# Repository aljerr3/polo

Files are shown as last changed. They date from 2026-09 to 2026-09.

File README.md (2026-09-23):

# 🪲 POLO — Walking Beetle Robot / Escarabajo Robot Caminante

<p align="center">
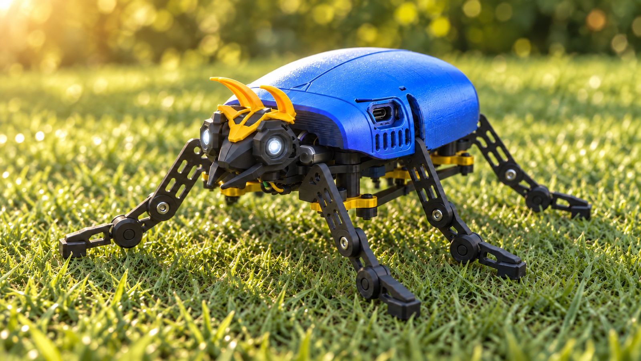
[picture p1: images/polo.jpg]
POLO — Walking Beetle Robot
  
</p>

<p align="center">
  <b><a href="#-english">🇬🇧 English</a> · <a href="#-español">🇪🇸 Español</a></b>
</p>

---

## 🇬🇧 English

Can a six-legged robot be made to walk with just three motors? **POLO** is a **fully 3D-printable** beetle robot, inspired by the *pololo* —a Chilean beetle— and by the minimalist walkers of **Mark Tilden**, to whom this project pays tribute.

This isn't just an electronics project. It's an exercise in mechanics: print-in-place ball joints, lobular couplers, connecting rods and a central rocker that, together, make six legs move in a fluid, almost organic way.

### 🎯 What does this robot do?

- Walks forward, backward and turns using **only 3 servos**
- Controlled from your phone **over WiFi, no apps**, straight from the browser
- Has **4 walking speeds**: very fast, fast, slow and stealthy
- Its eyes pulse, simulating a beetle's heartbeat
- Emits **stridulation** sounds through a buzzer, just like real beetles
- Charges via **USB-C** without removing the shell

### ⚙️ Main components

| Component | Detail |
|---|---|
| Microcontroller | ESP32-C3 Super Mini |
| Actuators | 3 × SG90 servos |
| Battery | 803040 LiPo, 1000 mAh (3.7 V) |
| Power management | PB0063A module (IP5306): charging, protection and 5 V boost |
| Filtering | 470 µF electrolytic capacitor |
| Eyes | 2 × 5 mm LEDs |
| Sound | Passive buzzer |
| PCB | POLO PCB (manufactured by PCBWay) or hand-built on perfboard |
| Structure | 3D-printed parts (PLA) |

### 🧠 Philosophy behind the project

Today electronics and software are within anyone's reach, especially with the help of AI. Mechanics, on the other hand, still surprises. That's why the heart of POLO is not in the code, but in how its parts move.

The robot draws on **BEAM**, Mark Tilden's philosophy: achieving complex behaviors with the fewest possible components. One servo moves both legs on the left side, another the right side, and a third drives a central rocker that tilts the body to lift the legs on the opposite side.

POLO is also a learning project. A walker like this can be made with 2 servos, and probably better. This is my path toward that, and I'm sharing it in full so others can improve it.

### 🔩 Mechanical features

- **100% printable**: all structural parts are 3D-printed
- Print-in-place articulated ball joints, in a single piece and **without supports**: the ankle drops about 45° when the leg lifts and self-levels when it lands
- Elongated flat-soled feet for better traction
- Indexed 10-lobe lobular couplers (36° steps) to adjust the position of each tibia
- Mechanical connecting rods and a central rocker driven by the same 3 servos
- Topology optimization to reduce weight, material and power consumption
- Elytra-style shell screwed to the chassis, with openings for the USB-C ports
- Snap-on helmet with horns that double as antennae
- Size: about **12.6 cm** from leg tip to leg tip

### 📡 Technical features

- **WiFi in access-point mode**: the robot creates its own network, no router needed
- Responsive web interface with two views: **control** and **configuration**
- Low-latency control: hold an arrow to walk and release to return to rest
- Servo calibration and gait routines (angles and speed) from the browser
- Default values measured with an oscilloscope, ready for anyone who can't calibrate
- Independent control of each eye with PWM dimming
- Free **I2C (Qwiic)** port so you can add your own sensors
- Measured consumption: **~0.36 A at 5 V (1.75 W)**

### 🔌 Electrical connections

**ESP32-C3 Super Mini:**

| GPIO | Function |
|---|---|
| GPIO 4 | Left leg servo |
| GPIO 3 | Right leg servo |
| GPIO 2 | Central rocker servo |
| GPIO 10 | LED eye 1 (cathode; anode to 5 V through a resistor) |
| GPIO 1 | LED eye 2 (cathode; anode to 5 V through a resistor) |
| GPIO 7 | Buzzer (signal S) |
| GPIO 5 | SDA (Qwiic port) |
| GPIO 6 | SCL (Qwiic port) |

**Power:** LiPo battery → IP5306 module → 5 V rail. The ESP32 and the 3 servos share the 5 V rail, with a 470 µF capacitor.

See the full schematic in [`hardware/Esquematico.png`](hardware/Esquematico.png).

### 🛠️ Build your own PCB with PCBWay

POLO's board is designed to fit exactly into the chassis. It's 2-layer and measures **50.1 × 40.3 mm**, with an outline cut to the robot's shape. It has a black solder mask and white silkscreen, easy-to-solder through-hole components, ground planes on both sides and two USB-C ports (charging and programming).

Thanks to **PCBWay**, sponsor of this project's PCB, you can order the same board directly from their platform. The Gerber files are in [`hardware/Gerber_POLO_PCB.zip`](hardware/Gerber_POLO_PCB.zip).

If you prefer to build it by hand, POLO's first prototype worked perfectly on **perfboard**.

### 🚀 Installation and setup

1. Print the parts (recommended: PLA, 0.12 mm layer height; the ball-jointed tibias are printed flat-side down on the bed, without supports)
2. Solder the PCB or build the circuit on perfboard according to the schematic
3. Flash the firmware ([`firmware/POLO_v7_1.ino`](firmware/POLO_v7_1.ino)) onto the ESP32-C3 via the programming USB-C port
4. Mount the servos in their rest position before attaching the legs
5. Power on POLO and connect from your phone to its WiFi network
6. Open the robot's IP in your browser
7. In the configuration view, adjust the rest position and gait if needed
8. Switch to the control view and make it walk!

**Customizable configuration (from the web):** rest position of each servo (default **60° / 111° / 68°**), swing angles for forward/backward/turn, gait period (default **700 ms**), walking speeds, and eyes on/off + brightness.

### 📁 Repository contents

```
polo/
├── firmware/
│   └── POLO_v7_1.ino          # Firmware for the ESP32-C3
├── hardware/
│   ├── Esquematico.png         # Circuit schematic
│   ├── PCB_Diseno.png          # PCB design
│   └── Gerber_POLO_PCB.zip     # Gerber files for manufacturing
├── 3d/
│   ├── POLO.step               # Full CAD model (Fusion 360 / STEP)
│   ├── POLO_impresion_orcaslicer.3mf  # OrcaSlicer print profile & plate layout
│   ├── polo-stl.zip            # All STL parts
│   └── stl/                    # Individual STL parts
└── images/                     # Robot photos
```

> **3D printing:** the CAD model, STL files and my OrcaSlicer print profile are in [`3d/`](3d/). **Please read the [printing notes and disclaimer](3d/README.md) first.**

### 🧰 Technologies

ESP32-C3 · SG90 servos · 3D printing · Fusion 360 · EasyEDA · PCBWay · WiFi AP · Embedded web server · PWM · I2C

### 📜 License

This project is released under the **MIT** license. You can modify, adapt and improve it. See [LICENSE](LICENSE).

---

## 🇪🇸 Español

¿Se puede hacer caminar un robot de seis patas con solo tres motores? **POLO** es un escarabajo robot **100% imprimible**, inspirado en el *pololo* —un escarabajo chileno— y en los caminantes minimalistas de **Mark Tilden**, a quien este proyecto rinde tributo.

Este no es solo un proyecto de electrónica. Es un ejercicio de mecánica: rótulas impresas en una sola pieza, acoples lobulares, bielas y un balancín que, juntos, hacen que seis patas se muevan de forma fluida y casi orgánica.

### 🎯 ¿Qué hace este robot?

- Camina hacia adelante, hacia atrás y gira usando **solo 3 servos**
- Se controla desde el celular **por WiFi, sin apps**, directo desde el navegador
- Tiene **4 velocidades de marcha**: muy rápido, rápido, lento y sigiloso
- Sus ojos pulsan simulando el latido del corazón de un escarabajo
- Emite sonidos de **estridulación** con un buzzer, igual que los escarabajos reales
- Se carga por **USB-C** sin quitar el caparazón

### ⚙️ Componentes principales

| Componente | Detalle |
|---|---|
| Microcontrolador | ESP32-C3 Super Mini |
| Actuadores | 3 servos SG90 |
| Batería | LiPo 803040 de 1000 mAh (3,7 V) |
| Gestión de energía | Módulo PB0063A (IP5306): carga, protección y elevador a 5 V |
| Filtrado | Condensador electrolítico de 470 µF |
| Ojos | 2 LEDs de 5 mm |
| Sonido | Buzzer pasivo |
| PCB | POLO PCB (fabricada por PCBWay) o perfboard armada a mano |
| Estructura | Piezas impresas en 3D (PLA) |

### 🧠 Filosofía del proyecto

Hoy la electrónica y el software están al alcance de cualquiera, sobre todo con la ayuda de la IA. La mecánica, en cambio, sigue sorprendiendo. Por eso el corazón de POLO no está en el código, sino en cómo se mueven sus piezas.

El robot se inspira en **BEAM**, la filosofía de Mark Tilden: lograr comportamientos complejos con el mínimo de componentes. Un servo mueve las dos patas del lado izquierdo, otro las del lado derecho, y un tercero acciona un balancín central que inclina el cuerpo para levantar las patas del lado contrario.

POLO es también un proyecto de aprendizaje. Un caminante así se puede hacer con 2 servos, y probablemente mejor. Este es mi camino para llegar a él, y lo comparto completo para que otros lo mejoren.

### 🔩 Características mecánicas

- **100% imprimible**: todas las piezas estructurales son impresas en 3D
- Rótulas articuladas impresas en sitio, en una sola pieza y **sin soportes**: el tobillo cae unos 45° al levantar la pata y se autonivela al apoyar
- Pies de suela plana alargada para mejor tracción
- Acoples lobulares indexados de 10 lóbulos (pasos de 36°) para ajustar la posición de cada tibia
- Bielas mecánicas y balancín central movidos por los mismos 3 servos
- Optimización topológica para reducir peso, material y consumo
- Caparazón tipo élitro atornillado al chasis, con aberturas para los puertos USB-C
- Casco con cachos a presión, que hacen las veces de antenas
- Tamaño: unos **12,6 cm** de punta a punta de patas

### 📡 Características técnicas

- **WiFi en modo punto de acceso**: el robot crea su propia red, sin necesidad de router
- Interfaz web responsive con dos vistas: **manejo** y **configuración**
- Control de baja latencia: mantén presionada una flecha para caminar y suelta para volver a reposo
- Calibración de servos y rutinas de marcha (ángulos y velocidad) desde el navegador
- Valores por defecto medidos con osciloscopio, listos para quien no pueda calibrar
- Control independiente de cada ojo con atenuación por PWM
- Puerto **I2C (Qwiic)** libre para agregar tus propios sensores
- Consumo medido: **~0,36 A a 5 V (1,75 W)**

### 🔌 Conexiones eléctricas

**ESP32-C3 Super Mini:**

| GPIO | Función |
|---|---|
| GPIO 4 | Servo pata izquierda |
| GPIO 3 | Servo pata derecha |
| GPIO 2 | Servo balancín central |
| GPIO 10 | LED ojo 1 (cátodo; ánodo a 5 V con resistencia) |
| GPIO 1 | LED ojo 2 (cátodo; ánodo a 5 V con resistencia) |
| GPIO 7 | Buzzer (señal S) |
| GPIO 5 | SDA (puerto Qwiic) |
| GPIO 6 | SCL (puerto Qwiic) |

**Alimentación:** Batería LiPo → módulo IP5306 → riel de 5 V. El ESP32 y los 3 servos comparten el riel de 5 V, con un condensador de 470 µF.

Ver el esquemático completo en [`hardware/Esquematico.png`](hardware/Esquematico.png).

### 🛠️ Fabrica tu propia PCB con PCBWay

La placa de POLO está diseñada para encajar exactamente en el chasis. Es de 2 capas y mide **50,1 x 40,3 mm**, con contorno recortado a la forma del robot. Lleva máscara negra y serigrafía blanca, componentes through-hole fáciles de soldar, planos de masa en ambas caras y dos puertos USB-C (carga y programación).

Gracias a **PCBWay**, patrocinador de la PCB de este proyecto, puedes pedir la misma placa directamente desde su plataforma. Los archivos Gerber están en [`hardware/Gerber_POLO_PCB.zip`](hardware/Gerber_POLO_PCB.zip).

Si prefieres armarla a mano, el primer prototipo de POLO funcionó perfectamente sobre **perfboard**.

### 🚀 Instalación y configuración

1. Imprime las piezas (recomendado: PLA, capa 0,12 mm; las tibias con rótula se imprimen con la cara plana sobre la cama, sin soportes)
2. Suelda la PCB o arma el circuito en perfboard según el esquema
3. Carga el firmware ([`firmware/POLO_v7_1.ino`](firmware/POLO_v7_1.ino)) en el ESP32-C3 por el puerto USB-C de programación
4. Monta los servos en su posición de reposo antes de fijar las patas
5. Enciende POLO y conéctate desde tu celular a su red WiFi
6. Abre la IP del robot en el navegador
7. En la vista de configuración, ajusta el reposo y la marcha si lo necesitas
8. ¡Pasa a la vista de manejo y hazlo caminar!

**Configuración personalizable (desde la web):** posición de reposo de cada servo (por defecto **60° / 111° / 68°**), ángulos de oscilación para avanzar/retroceder/girar, periodo de la marcha (por defecto **700 ms**), velocidades de marcha, y encendido/brillo de los ojos.

### 📁 Contenido del repositorio

```
polo/
├── firmware/
│   └── POLO_v7_1.ino          # Firmware para el ESP32-C3
├── hardware/
│   ├── Esquematico.png         # Esquemático del circuito
│   ├── PCB_Diseno.png          # Diseño de la PCB
│   └── Gerber_POLO_PCB.zip     # Archivos Gerber para fabricación
├── 3d/
│   ├── POLO.step               # Modelo CAD completo (Fusion 360 / STEP)
│   ├── POLO_impresion_orcaslicer.3mf  # Perfil de impresión OrcaSlicer y bandeja
│   ├── polo-stl.zip            # Todas las piezas STL
│   └── stl/                    # Piezas STL individuales
└── images/                     # Fotos del robot
```

> **Impresión 3D:** el modelo CAD, los STL y mi perfil de impresión de OrcaSlicer están en [`3d/`](3d/). **Lee primero las [notas de impresión y el aviso](3d/README.md).**

### 🧰 Tecnologías

ESP32-C3 · Servos SG90 · Impresión 3D · Fusion 360 · EasyEDA · PCBWay · WiFi AP · Servidor web embebido · PWM · I2C

### 📜 Licencia

Este proyecto está bajo la licencia **MIT**. Puedes modificarlo, adaptarlo y mejorarlo. Ver [LICENSE](LICENSE).

---

Made by / Hecho por **Alejandro Jesús Rodríguez Radomile** · [rodriguezalejandro.com](https://rodriguezalejandro.com)

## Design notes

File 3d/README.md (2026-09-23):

# 🖨️ POLO — 3D Files & Printing / Archivos 3D e Impresión

<p align="center">
  <b><a href="#-english">🇬🇧 English</a> · <a href="#-español">🇪🇸 Español</a></b>
</p>

## 📁 Contents / Contenido

| File / Archivo | Description / Descripción |
|---|---|
| `POLO.step` | Full CAD model (Fusion 360 / STEP) — editable / Modelo CAD completo, editable |
| `POLO_impresion_orcaslicer.3mf` | OrcaSlicer project with print parameters & plate layout / Proyecto OrcaSlicer con parámetros y disposición en bandeja |
| `polo-stl.zip` | All STL parts in one download / Todas las piezas STL en una descarga |
| `stl/` | Individual STL parts / Piezas STL individuales |

---

## 🇬🇧 English

### ⚠️ Disclaimer

These are the print parameters **that worked for me** — they do **not** mean they are a standard suitable for every printer, filament or setup. Use them as a reference. The final result is **each person's own responsibility**.

The parts come **arranged on a single plate to optimize the print and make it faster**. However, if you want to **customize or tweak individual parts**, it is recommended to print them on **separate plates**.

### 🧾 Recommended (reference)

- Material: PLA
- Layer height: 0.12 mm
- The ball-jointed tibias print **flat-side down on the bed, without supports** (the joint is printed in place)

Open `POLO_impresion_orcaslicer.3mf` in [OrcaSlicer](https://github.com/SoftFever/OrcaSlicer) to see the exact profile and plate layout I used.

---

## 🇪🇸 Español

### ⚠️ Aviso

Estos son los parámetros de impresión **que a mí me funcionaron** — **no** quiere decir que sean un estándar válido para toda impresora, filamento o configuración. Tómalos como referencia. El resultado final es **responsabilidad de cada quien**.

Las piezas vienen **ordenadas en una sola bandeja para optimizar la impresión y hacerla más rápida**. Sin embargo, si quieres **personalizar o ajustar piezas individuales**, se recomienda imprimirlas en **bandejas distintas**.

### 🧾 Recomendado (referencia)

- Material: PLA
- Altura de capa: 0,12 mm
- Las tibias con rótula se imprimen **con la cara plana sobre la cama, sin soportes** (la rótula se imprime en sitio)

Abre `POLO_impresion_orcaslicer.3mf` en [OrcaSlicer](https://github.com/SoftFever/OrcaSlicer) para ver el perfil exacto y la disposición en bandeja que usé.

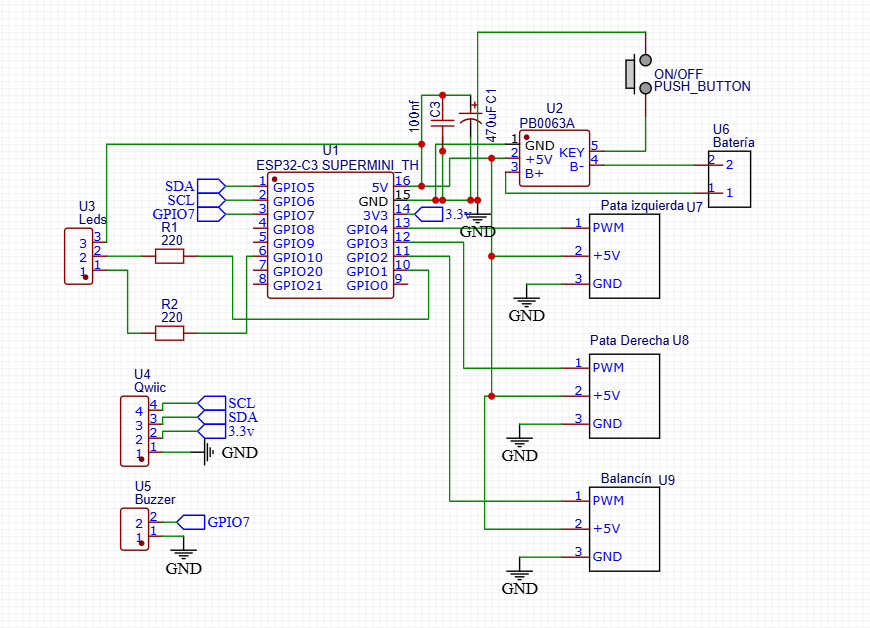
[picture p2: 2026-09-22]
hardware/Esquematico.png

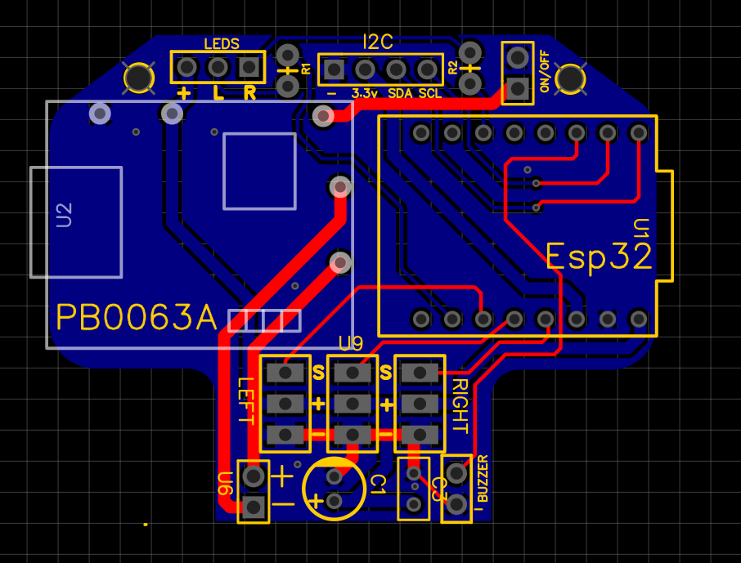
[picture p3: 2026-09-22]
hardware/PCB_Diseno.png

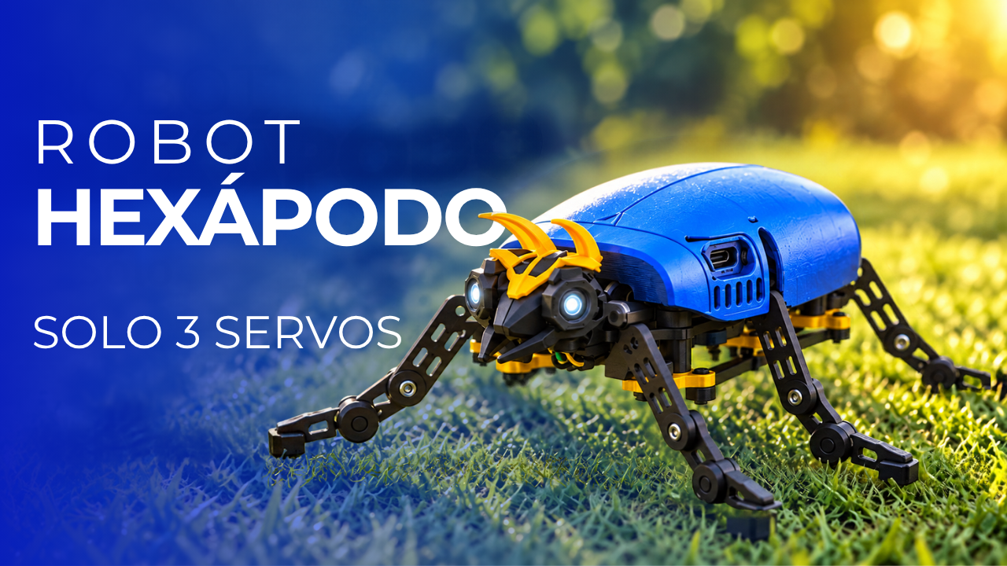
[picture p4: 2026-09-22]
images/polo-2.png

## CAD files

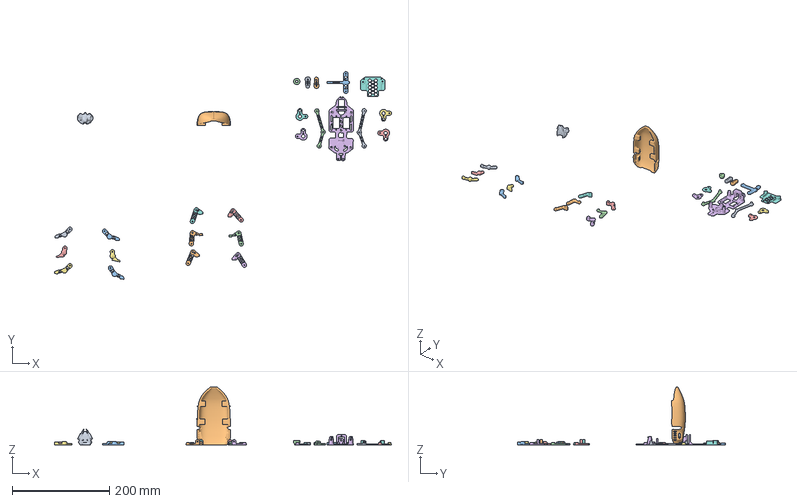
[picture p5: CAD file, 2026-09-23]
3d/POLO_impresion_orcaslicer.3mf
691.6 x 426.5 x 118.9 mm
Cabeza.stl
Femur derecho (Balancín).stl
Tibia pata izquierda delantera.stl
Femur izquierdo Balancín.stl
Femur pata izquierda delantera.stl
femur derecho pata delantera.stl
tibia pata derecha delantera.stl
Femur pata derecha trasera.stl
Biela derecha.stl
Femur pata izquierda trasera.stl
Tibia pata derecha trasera.stl
Biela izquierda_.stl
Tibía Balancín izquierda.stl
chásis final v1.stl
Tibia Balancín Derecha.stl
Sosten batería.stl
Horn Servo derecho.stl
Horn servo izquierdo.stl
Eje Balancín.stl
Eje acople central (Balancín).stl
Acoples lobulares.stl_1
Acoples lobulares.stl_2
Acoples lobulares.stl_3
Acoples lobulares.stl_4
Tibia pata izquierda trasera.stl
caparazón final.stl

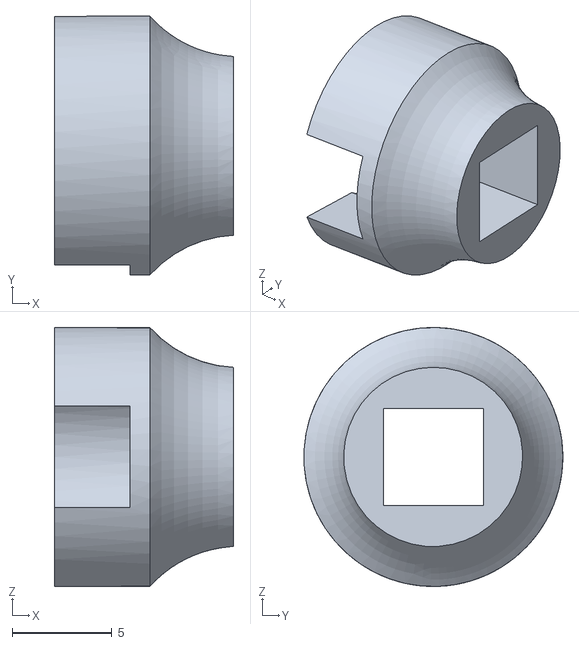
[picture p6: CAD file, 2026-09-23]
3d/stl/Eje acople central (Balancín).stl
9.00 x 13.0 x 13.0

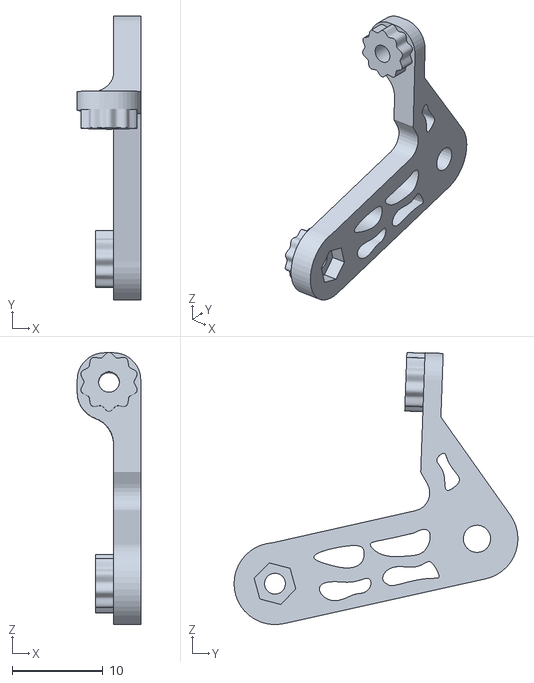
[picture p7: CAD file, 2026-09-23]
3d/stl/Femur derecho (Balancín).stl
7.00 x 31.2 x 29.9

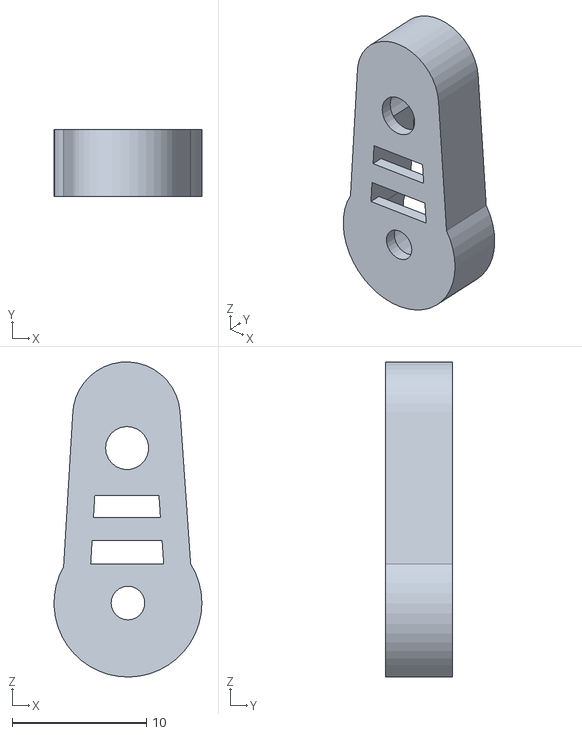
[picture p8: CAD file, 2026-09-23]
3d/stl/Horn Servo derecho.stl
11.0 x 5.00 x 23.4

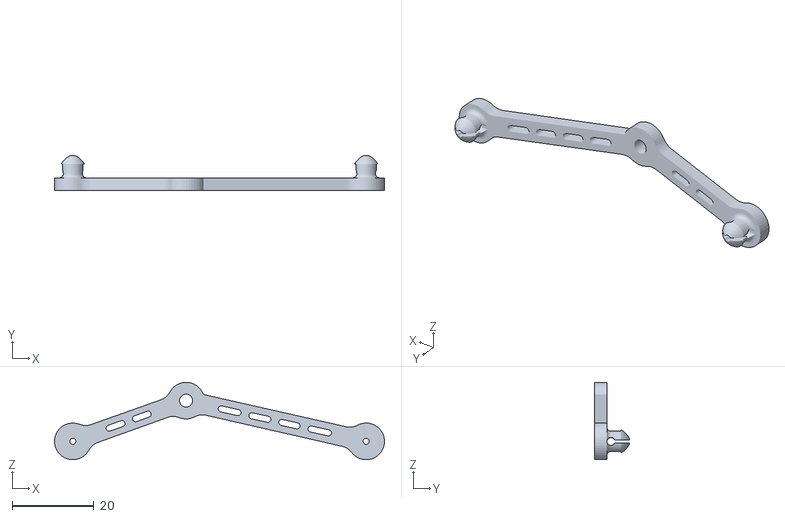
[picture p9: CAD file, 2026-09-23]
3d/stl/Biela izquierda_.stl
81.0 x 8.50 x 19.0

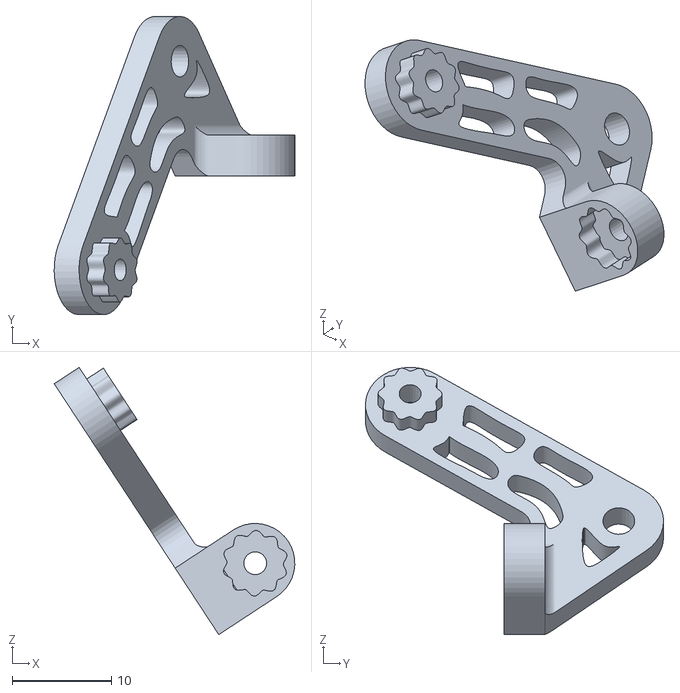
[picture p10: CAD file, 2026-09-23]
3d/stl/Femur pata derecha trasera.stl
24.2 x 30.0 x 26.9

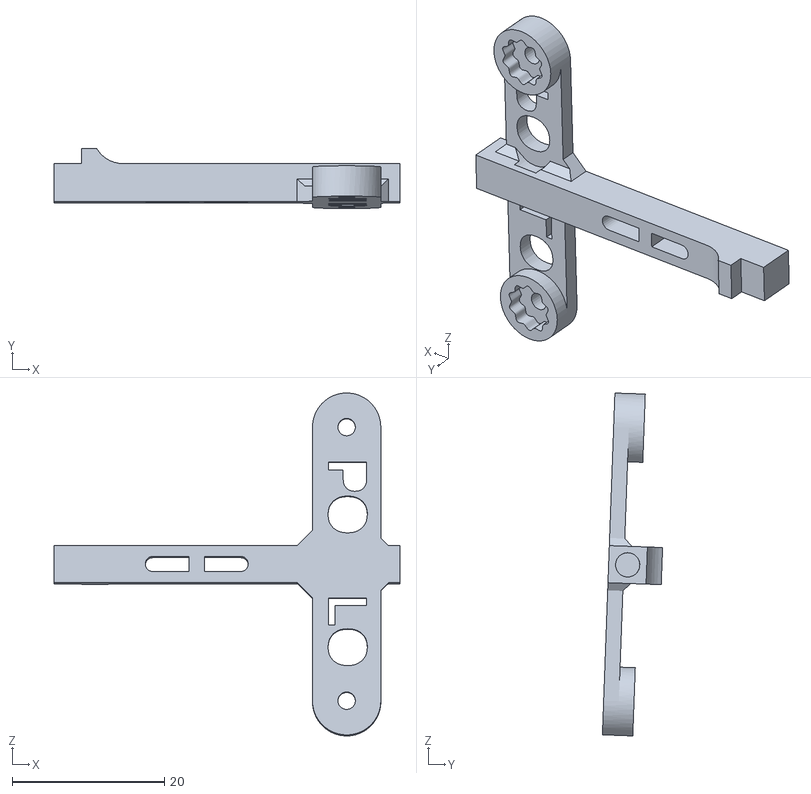
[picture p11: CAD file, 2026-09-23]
3d/stl/Eje Balancín.stl
45.5 x 7.92 x 45.1

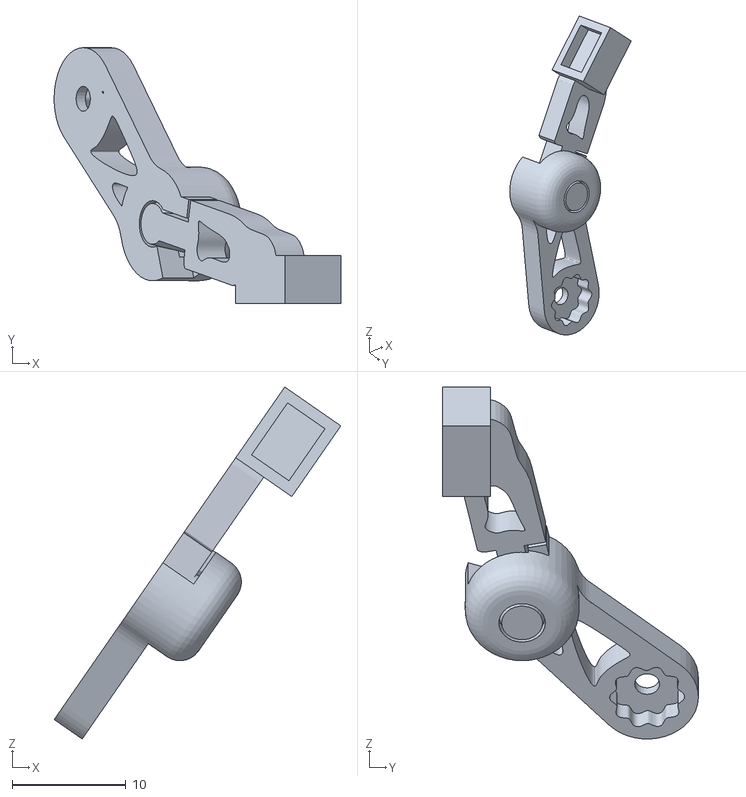
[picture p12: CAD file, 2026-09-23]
3d/stl/tibia pata derecha delantera.stl
25.2 x 22.5 x 30.9

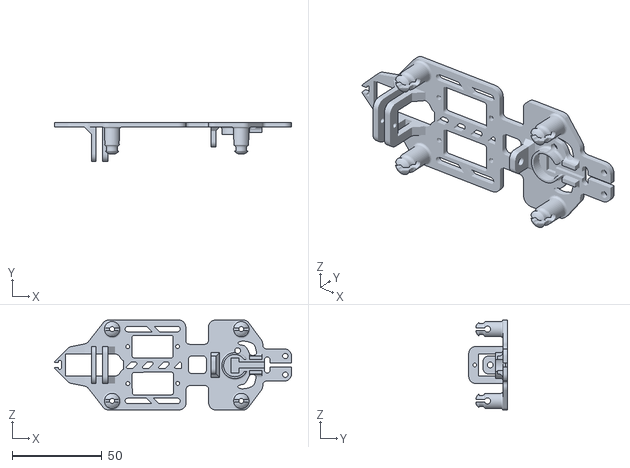
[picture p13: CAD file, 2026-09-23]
3d/stl/chásis final v1.stl
132.1 x 21.5 x 50.1

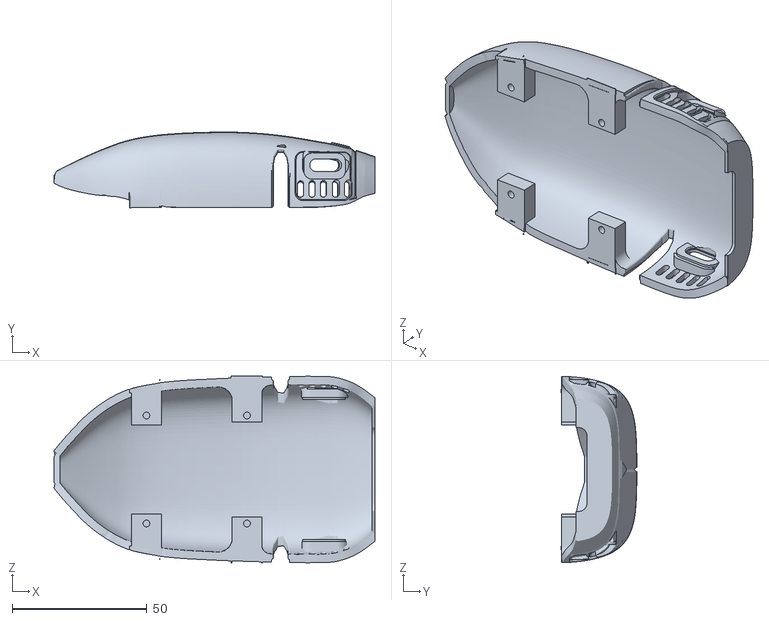
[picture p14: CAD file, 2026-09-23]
3d/stl/caparazón final.stl
118.9 x 28.1 x 69.2

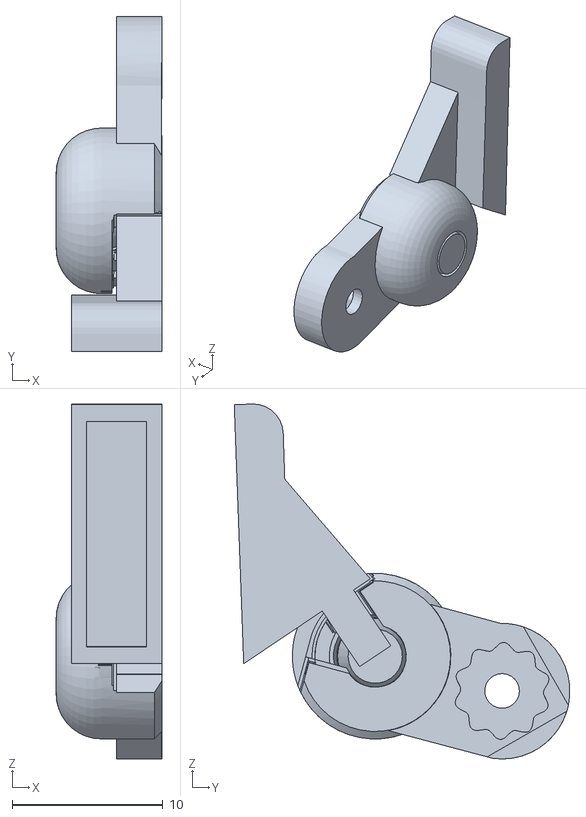
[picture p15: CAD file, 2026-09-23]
3d/stl/Tibia Balancín Derecha.stl
7.03 x 22.3 x 23.6

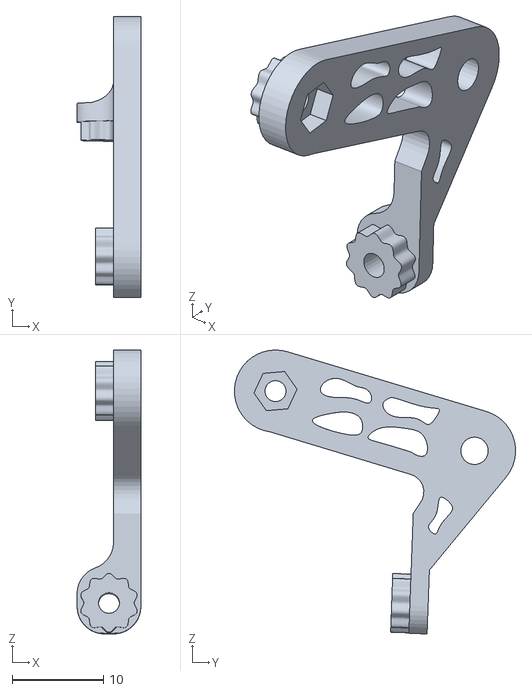
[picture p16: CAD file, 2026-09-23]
3d/stl/Femur izquierdo Balancín.stl
7.00 x 30.8 x 31.1

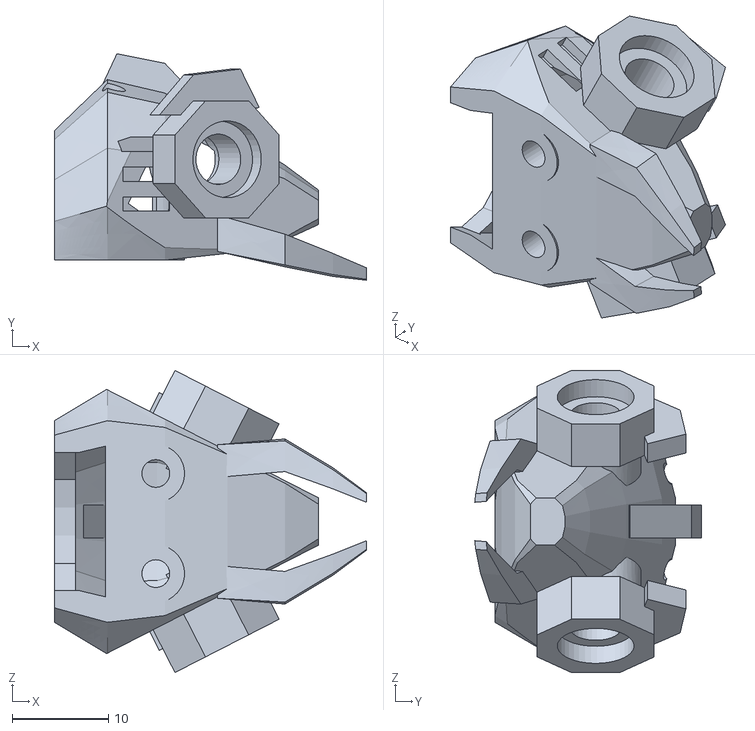
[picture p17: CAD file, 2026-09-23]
3d/stl/Cabeza.stl
32.5 x 23.6 x 31.5

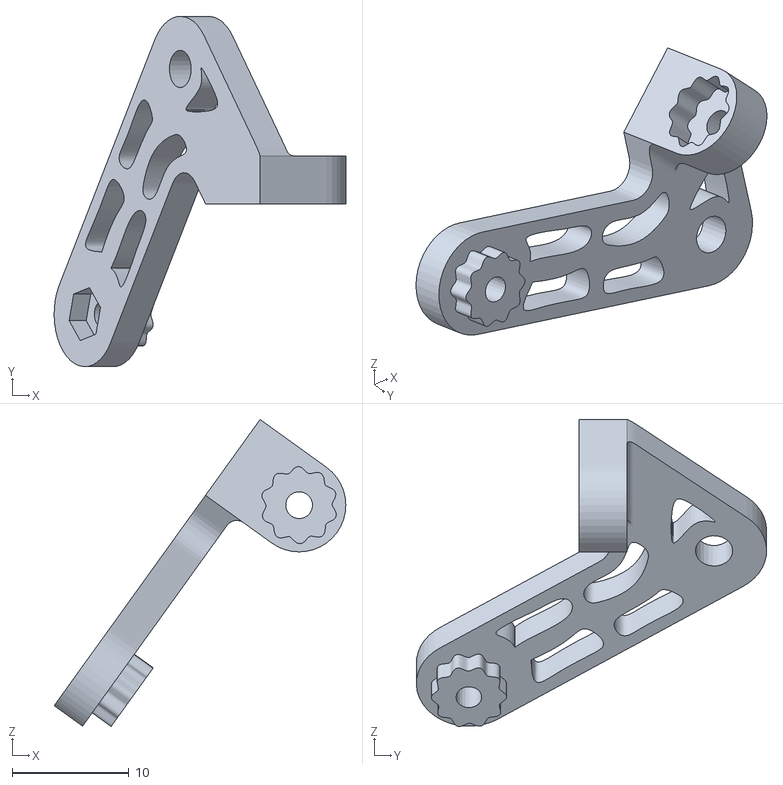
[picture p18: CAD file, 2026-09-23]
3d/stl/Femur pata izquierda delantera.stl
25.0 x 30.0 x 26.3

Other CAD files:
3d/stl/Biela derecha.stl
3d/stl/Tibia pata derecha trasera.stl
3d/stl/Caparazón.stl
3d/stl/Tibía Balancín izquierda.stl
3d/stl/Acoples lobulares.stl
3d/stl/Femur pata izquierda trasera.stl
3d/stl/Horn servo izquierdo.stl
3d/stl/POLO.stl
3d/stl/Sosten batería.stl
3d/stl/Tibia pata izquierda delantera.stl
3d/stl/femur derecho pata delantera.stl

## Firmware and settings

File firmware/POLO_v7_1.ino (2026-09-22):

/*
 * ============================================================
 *  POLO — ROBOT CAMINANTE — ESP32-C3 Super Mini — v7.1
 *
 *  NOVEDADES DE v7.1: PINES DE SERVOS SEGÚN LA PCB
 *   En la PCB ensamblada los servos quedaron en otros pines que en el
 *   prototipo. El mapeo correcto ahora es:
 *       Pata izquierda → GPIO2
 *       Pata derecha   → GPIO4
 *       Balancín       → GPIO3
 *   Solo cambian los pines. El orden en la interfaz, los índices
 *   internos y los valores guardados siguen siendo los mismos, así que
 *   cada control vuelve a mover el servo que dice su nombre.
 *
 *  NOVEDADES DE v7: ESTRIDULACIÓN Y OJOS
 *   · Buzzer pasivo en GPIO7 que simula el raspado de un escarabajo.
 *     Tres modos: continuo, un chirrido por paso, o al arrancar y parar.
 *     Cuatro presets de partida y todos los parámetros ajustables.
 *   · Dos ojos LED independientes en GPIO10 y GPIO1, con latido de dos
 *     picos tipo lub-dub, corrección de gamma y opción de sincronizarse
 *     con la marcha: un latido por paso.
 *   · Todo se guarda en la memoria del micro, así que cada quien deja
 *     su propia configuración de sonido y de ojos.
 *   · Interruptores de sonido y ojos en la pantalla de manejo.
 *
 *  CABLEADO DE LO NUEVO
 *     Buzzer pasivo (módulo de 3 pines):  S → GPIO7 · centro → 5V · − → GND
 *     Ojo izquierdo:  +5V ── LED ── 220 Ω ── GPIO10
 *     Ojo derecho:    +5V ── LED ── 220 Ω ── GPIO1
 *   Los LEDs cuelgan del riel de 5 V y el pin drena la corriente. El
 *   código ya invierte la lógica y para apagarlos del todo suelta el
 *   canal y deja el pin en entrada, que es lo que garantiza que
 *   funcionen con LEDs de cualquier color.
 *
 *  Dos vistas:
 *   · MANEJO (pantalla principal): cruceta de 4 flechas y 5 niveles
 *     de velocidad. Mantener presionada una flecha hace caminar,
 *     soltarla devuelve el robot a reposo.
 *   · CONFIGURACIÓN: calibración, recorridos, fases, forma de onda,
 *     gráfica del ciclo y ajustes finos.
 *
 *  FORMA DE ONDA POR SERVO (novedad de v4)
 *   El balancín es un mecedor simétrico: no tiene carrera de apoyo ni
 *   de vuelo, las dos mitades del ciclo cumplen la misma función. Una
 *   onda asimétrica le da más tiempo de suelo a un lado que al otro,
 *   y eso se ve exactamente como una cojera. Por eso ahora cada servo
 *   elige su forma:
 *     · BALANCEO — simétrica, con pausa en los extremos. Mantiene la
 *       inclinación mientras las patas levantadas avanzan, y cambia
 *       de lado rápido. (Para el balancín.)
 *     · EMPUJE   — barrido de velocidad casi constante en la carrera
 *       cargada y retorno suavizado, ambas mitades de igual duración.
 *       (Para los servos de patas.)
 *
 *   Las patas de este robot no se levantan solas: las levanta el
 *   balancín, y lo hace en un reparto estricto de 50/50. Por eso las
 *   carreras de apoyo y vuelo de cada pata duran exactamente medio
 *   ciclo cada una, y lo único que se puede cambiar es su forma.
 *
 *  SALIDA DE MONITOREO PARA OSCILOSCOPIO (novedad de v5)
 *   Tres pines nuevos que no mueven nada — solo permiten ver el
 *   movimiento en un osciloscopio:
 *     GPIO5  → canal 1   |  GPIO6  → canal 2
 *       PWM de 20 kHz cuyo ciclo de trabajo sigue el ángulo real
 *       comandado al servo. Con un filtro RC (4,7 kΩ + 1 µF) se
 *       convierte en una tensión de 0 a 3,3 V: la onda de marcha
 *       tal cual, lista para medir con los cursores.
 *     GPIO7  → sincronía
 *       Onda cuadrada de un pulso por ciclo. Va directo a la sonda,
 *       sin filtro, y sirve para disparar el osciloscopio de forma
 *       estable. Alta durante la primera mitad del ciclo.
 *
 *   Qué servo sale por cada canal se elige en Ajustes finos.
 *   La escala es automática: cada canal usa el recorrido del servo
 *   más un 25 % de margen, así la onda ocupa casi toda la pantalla
 *   sin llegar nunca a los topes.
 *
 *  Librerías (Gestor de librerías del IDE):
 *   - ESP32Servo   (Kevin Harrington / John K. Bennett)
 *   - WebSockets   (Markus Sattler)
 *  Placa: "ESP32C3 Dev Module" · USB CDC On Boot: Enabled
 *
 *  Uso: conectarse a la red "POLO" (clave robot1234)
 *       y abrir http://192.168.4.1
 *
 *  NOTA: las rutinas guardadas en v4 siguen siendo válidas. Solo se
 *  reinician los ajustes finos, porque su estructura creció.
 * ============================================================
 */

#include <WiFi.h>
#include <WebServer.h>
#include <DNSServer.h>
#include <ESP32Servo.h>
#include <Preferences.h>
#include <WebSocketsServer.h>

// ==================================================
//  RED (modo AP)
// ==================================================
const char* AP_SSID  = "POLO";
const char* AP_PASS  = "robot1234";     // mínimo 8 caracteres
const int   AP_CANAL = 6;               // 1, 6 u 11 — usar el más limpio
const int   AP_MAX_CLIENTES = 2;

IPAddress AP_IP(192, 168, 4, 1);
IPAddress AP_MASK(255, 255, 255, 0);

DNSServer        dns;
WebServer        server(80);
WebSocketsServer ws(81);
Preferences      prefs;

// ==================================================
//  PINES
// ==================================================
/*  Mapeo según la PCB (v7.1). En el prototipo eran 4 / 3 / 2.
 *  Si algún día cambia el ruteo, este es el único lugar que hay que tocar:
 *  el resto del firmware y la interfaz trabajan por índice
 *  (0 = pata izquierda, 1 = pata derecha, 2 = balancín).
 */
#define PIN_PATA_IZQ 2
#define PIN_PATA_DER 4
#define PIN_BALANCIN 3
#define N_SERVOS 3

const int PINES[N_SERVOS] = {PIN_PATA_IZQ, PIN_PATA_DER, PIN_BALANCIN};

const int US_MIN = 500;    // ancho de pulso del SG90
const int US_MAX = 2400;

// --- ojos y buzzer ---
#define PIN_LED_I  10      // ojo izquierdo:  +5V - LED - 220Ω - GPIO10
#define PIN_LED_D  1       // ojo derecho:    +5V - LED - 220Ω - GPIO1
#define PIN_BUZZER 7       // buzzer pasivo (módulo de 3 pines: S aquí)

#define PWM_BITS 10
#define PWM_MAX  1023

/*  PRESUPUESTO DE CANALES PWM
 *  El ESP32-C3 tiene exactamente 6 canales LEDC y aquí se usan los 6:
 *      3 servos + 2 ojos + 1 buzzer
 *  Por eso las salidas de monitoreo para osciloscopio de v5/v6 están
 *  desactivadas: sus pines GPIO5 y GPIO6 pasaron a ser el bus I2C, y
 *  además no quedan canales libres.
 *
 *  Poner MONITOR_OSC en 1 las revive para filmar formas de onda, pero
 *  a cambio APAGA los ojos (libera sus dos canales) y deja el I2C
 *  inutilizable mientras esté activo. Es un modo de laboratorio.
 */
#define MONITOR_OSC 0

#if MONITOR_OSC
  #define PIN_MON_A    5
  #define PIN_MON_B    6
  #define MON_FREQ 20000
  #if ESP_ARDUINO_VERSION_MAJOR >= 3
    #define MON_CH_A PIN_MON_A
    #define MON_CH_B PIN_MON_B
  #else
    #define MON_CH_A 4
    #define MON_CH_B 5
  #endif
#endif

#if ESP_ARDUINO_VERSION_MAJOR >= 3
  #define CH_LED_I  PIN_LED_I
  #define CH_LED_D  PIN_LED_D
  #define CH_BUZZER PIN_BUZZER
#else
  #define CH_LED_I  3        // los servos ocupan los canales LEDC 0-2
  #define CH_LED_D  4
  #define CH_BUZZER 5
#endif

// ==================================================
//  ESTRUCTURAS
// ==================================================
struct OscParam {
  float   angMin, angMax, fase;
  bool    activo, invertir;
  uint8_t forma;       // 0 = balanceo (simétrica), 1 = empuje (barrido + retorno)
};

struct Marcha {
  OscParam osc[N_SERVOS];
  uint16_t periodo;    // ms por ciclo (modo configuración y nivel "Normal")
  float    pausa;      // 0.00-0.60 — fracción del ciclo detenida en los extremos
  float    amplitud;   // 0.00-1.20 — escala global
};

struct Config {
  float    velMax[N_SERVOS];  // °/s máximo de cada servo, con su carga real
  uint16_t msBlend;           // transición marcha <-> reposo
  bool     silencio;          // corta el PWM cuando está quieto
  uint8_t  monA;              // servo que sale por el canal 1 del osciloscopio
  uint8_t  monB;              // servo que sale por el canal 2
};

/*  ESTRIDULACIÓN
 *  Un escarabajo no emite un tono: frota un rascador contra una lima de
 *  dientes y cada diente produce un chasquido. Lo que se oye es un tren
 *  de pulsos. De ahí las tres capas:
 *    portadora → el tono de cada chasquido (2-4 kHz, donde el piezo suena)
 *    pulsoHz   → cuántos chasquidos por segundo. Esta capa es la que
 *                convierte el pitido en raspado; es la que más importa.
 *    frase     → ráfagas agrupadas y silencio. Nada vivo chirría continuo.
 */
struct Sonido {
  uint16_t portadora;   // Hz
  uint8_t  varPct;      // % de azar en la portadora
  uint16_t pulsoHz;     // pulsos por segundo
  uint8_t  dutyPct;     // % encendido de cada pulso
  uint16_t chirpMs;     // duración de una ráfaga
  uint16_t gapMs;       // silencio entre ráfagas
  uint8_t  nChirps;     // ráfagas por frase
  uint16_t fraseMs;     // silencio entre frases
  int8_t   barridoPct;  // % que se mueve la portadora dentro de la ráfaga
  uint8_t  volPct;      // % de volumen
  uint8_t  modo;        // 0=continuo  1=un chirrido por paso  2=al arrancar y parar
  bool     activo;
};

struct Ojos {
  uint16_t bpm;         // latidos por minuto en reposo
  uint8_t  basePct;     // brillo entre latidos
  uint8_t  picoPct;     // brillo del pico
  bool     alterno;     // los dos ojos laten desfasados
  bool     conMarcha;   // caminando, el latido sigue el ritmo del paso
  bool     activo;
};

struct Nivel {
  const char* nombre;
  float facT;          // multiplica el periodo configurado por el usuario
  float facAmp;        // escala la amplitud
};

// 0 = más lento .. 4 = más rápido.
// "Normal" respeta exactamente el periodo guardado en configuración.
const Nivel NIVELES[5] = {
  { "Sigiloso",   2.60f, 0.62f },
  { "Lento",      1.60f, 0.95f },
  { "Normal",     1.00f, 1.00f },
  { "Rápido",     0.72f, 1.00f },
  { "Muy rápido", 0.50f, 1.00f }
};

// ==================================================
//  VALORES POR DEFECTO
// ==================================================
float anguloReposo[N_SERVOS] = {60, 111, 68};
float anguloActual[N_SERVOS] = {60, 111, 68};

Marcha marcha = {
  { { 53, 100,  75, true, false, 1 },   // Pata izquierda — empuje
    { 92, 150,  75, true, false, 1 },   // Pata derecha   — empuje
    { 60,  85,   0, true, false, 0 } }, // Balancín       — balanceo
  1400,       // periodo
  0.30f,      // pausa en extremos
  1.00f       // amplitud
};

/*  PROVISIONAL: estos tres valores son estimaciones de un SG90 con carga,
 *  no mediciones. El asistente de "Medir límite" los reemplaza con el
 *  valor real de cada servo. Al medirlos, copiarlos aquí para que salgan
 *  de fábrica en cualquier robot armado con este firmware.
 *      { pata izquierda, pata derecha, balancín }
 */
Config cfg = { {400.0f, 400.0f, 340.0f}, 400, true, 2, 0 };

//                portad var puls duty chirp gap n frase barr vol modo activo
Sonido snd = {      3200,  8,  90,  45,  220,  90, 3,  900, -12, 60,   1, true };
Ojos   ojos = { 72, 6, 100, false, true, true };

struct PresetSonido { const char* nombre; Sonido s; };
const PresetSonido PRESETS_SND[4] = {
  { "Chirrido", { 3200,  8,  90, 45, 220,  90, 3,  900, -12, 60, 1, true } },
  { "Rasgado",  { 2600, 15,  45, 55, 400, 150, 2, 1400, -25, 65, 1, true } },
  { "Clic",     { 4000,  5,  25, 20,  60, 200, 4, 1800,   0, 75, 1, true } },
  { "Zumbido",  { 2200, 20, 160, 60, 700,  60, 1, 1100, -35, 55, 1, true } }
};

const char* PRESET_IDS[4] = {"fw", "bk", "lf", "rt"};

// ==================================================
//  ESTADO
// ==================================================
Servo servos[N_SERVOS];
bool  enganchado[N_SERVOS] = {false, false, false};

float salida[N_SERVOS];
float objetivo[N_SERVOS];

bool    caminando      = false;
bool    modoConduccion = true;     // arranca en la pantalla de manejo
uint8_t nivelVel       = 2;        // "Normal"
bool    limitado       = false;    // el periodo pedido se recortó por saturación
char    dirActual      = 0;
uint8_t presetsBit     = 0;        // bit i = preset i guardado

float faseCiclo = 0.0f;            // 0..1, acumulada
float mezcla    = 0.0f;            // 0 = pose fija, 1 = marcha
float Tef       = 1400.0f;         // periodo efectivo en ms
float Aef       = 1.0f;            // amplitud efectiva
unsigned long tQuieto = 0;

// --- asistente de medición de límite ---
const float CAL_T_INI  = 2400.0f;  // ms por barrido al empezar
const float CAL_T_MIN  = 200.0f;   // ms por barrido al final
const float CAL_DECAY  = 0.955f;   // cuánto se acorta en cada barrido
const float CAL_MARGEN = 0.85f;    // se guarda el 85 % de lo marcado

int8_t calServo = -1;              // -1 = asistente apagado
float  calT     = CAL_T_INI;
float  calFase  = 0.0f;

// --- motor de estridulación ---
uint32_t sndTFase  = 0;
uint32_t sndTPulso = 0;
uint8_t  sndChirpN = 0;
bool     sndEnChirp = false;
bool     sndPulsoOn = false;
bool     sndFrase   = false;   // hay una frase en curso
bool     ledEnganchado = false;
float    faseLatido = 0.0f;
bool     caminabaAntes = false;

// ==================================================
//  PERSISTENCIA (NVS)
// ==================================================
void guardarReposo() {
  prefs.begin("robot", false);
  prefs.putBytes("m4_reposo", anguloReposo, sizeof(anguloReposo));
  prefs.end();
}
void guardarMarchaActual() {
  prefs.begin("robot", false);
  prefs.putBytes("m4_actual", &marcha, sizeof(marcha));
  prefs.end();
}
void guardarConfig() {
  prefs.begin("robot", false);
  prefs.putBytes("m6_cfg", &cfg, sizeof(cfg));
  prefs.end();
}
void guardarSonido() {
  prefs.begin("robot", false);
  prefs.putBytes("m7_snd", &snd, sizeof(snd));
  prefs.end();
}
void guardarOjos() {
  prefs.begin("robot", false);
  prefs.putBytes("m7_ojos", &ojos, sizeof(ojos));
  prefs.end();
}
void guardarPreset(int i) {
  prefs.begin("robot", false);
  prefs.putBytes(PRESET_IDS[i], &marcha, sizeof(marcha));
  prefs.end();
  presetsBit |= (1 << i);
}
bool cargarPreset(int i) {          // solo lectura, no desgasta la flash
  prefs.begin("robot", true);
  bool ok = prefs.getBytes(PRESET_IDS[i], &marcha, sizeof(marcha)) == sizeof(marcha);
  prefs.end();
  return ok;
}
void escanearPresets() {
  presetsBit = 0;
  prefs.begin("robot", true);
  for (int i = 0; i < 4; i++)
    if (prefs.getBytesLength(PRESET_IDS[i]) == sizeof(Marcha)) presetsBit |= (1 << i);
  prefs.end();
}
void cargarTodo() {
  prefs.begin("robot", true);
  prefs.getBytes("m4_reposo", anguloReposo, sizeof(anguloReposo));
  prefs.getBytes("m4_actual", &marcha, sizeof(marcha));
  prefs.getBytes("m6_cfg", &cfg, sizeof(cfg));
  prefs.getBytes("m7_snd", &snd, sizeof(snd));
  prefs.getBytes("m7_ojos", &ojos, sizeof(ojos));
  prefs.end();
  for (int i = 0; i < N_SERVOS; i++) {
    anguloActual[i] = anguloReposo[i];
    salida[i]       = anguloReposo[i];
    objetivo[i]     = anguloReposo[i];
  }
  escanearPresets();
}

// ==================================================
//  FORMAS DE ONDA
// ==================================================
float clampf(float v, float lo, float hi) { return v < lo ? lo : (v > hi ? hi : v); }
float clampAng(float a) { return clampf(a, 0.0f, 180.0f); }

float smoothstep(float u) {
  u = clampf(u, 0.0f, 1.0f);
  return u * u * (3.0f - 2.0f * u);
}

/*  Rampa de velocidad casi constante: acelera, mantiene, frena.
 *  Es lo que hace avanzar el cuerpo a ritmo parejo durante el apoyo.
 */
float rampaTrapecio(float t) {
  const float e = 0.25f;                    // fracción de aceleración en cada punta
  const float V = 1.0f / (1.0f - e);        // velocidad de crucero normalizada
  if (t <= 0.0f) return 0.0f;
  if (t >= 1.0f) return 1.0f;
  if (t < e)          return V * t * t / (2.0f * e);
  if (t < 1.0f - e)   return V * e * 0.5f + V * (t - e);
  float u = 1.0f - t;
  return 1.0f - V * u * u / (2.0f * e);
}

/*  Aplica la pausa en los extremos a un medio ciclo.
 *  t: 0..1 dentro del medio ciclo. Devuelve 0..1.
 */
float conPausa(float t, float p, bool suave) {
  p = clampf(p, 0.0f, 0.80f);
  float b = p * 0.5f;
  if (t <= b)          return 0.0f;
  if (t >= 1.0f - b)   return 1.0f;
  float u = (t - b) / (1.0f - p);
  return suave ? smoothstep(u) : rampaTrapecio(u);
}

/*  forma 0 = BALANCEO: las dos mitades son iguales y suaves.
 *      Arranca quieto, acelera, frena, se queda quieto, y vuelve igual.
 *  forma 1 = EMPUJE: primera mitad a velocidad casi constante (carrera
 *      cargada), segunda mitad de retorno suavizado. Igual duración.
 */
float ondaServo(float f, float pausa, uint8_t forma) {
  f = f - floorf(f);
  bool primera = (f < 0.5f);
  float t = (primera ? f : f - 0.5f) * 2.0f;
  if (forma == 0) {
    float v = conPausa(t, pausa, true);
    return primera ? v : 1.0f - v;
  }
  if (primera) return conPausa(t, pausa, false);
  return 1.0f - conPausa(t, pausa, true);
}

// ==================================================
//  SALIDA DE MONITOREO (solo con MONITOR_OSC en 1)
// ==================================================
#if MONITOR_OSC
void iniciarMonitor() {
#if ESP_ARDUINO_VERSION_MAJOR >= 3
  ledcAttach(PIN_MON_A, MON_FREQ, PWM_BITS);
  ledcAttach(PIN_MON_B, MON_FREQ, PWM_BITS);
#else
  ledcSetup(MON_CH_A, MON_FREQ, PWM_BITS);
  ledcAttachPin(PIN_MON_A, MON_CH_A);
  ledcSetup(MON_CH_B, MON_FREQ, PWM_BITS);
  ledcAttachPin(PIN_MON_B, MON_CH_B);
#endif
}
#endif

#if MONITOR_OSC
/*  Lleva el ángulo real de un servo a 0..1 usando su propio recorrido
 *  más un 25 % de margen. Así la onda ocupa casi toda la pantalla del
 *  osciloscopio sin tocar nunca los topes, sin importar si el servo
 *  recorre 25° o 60°. Si el servo no oscila, cae a la escala 0-180°.
 */
float normalizarServo(int i) {
  if (i < 0 || i >= N_SERVOS) return 0.0f;
  OscParam &o = marcha.osc[i];
  float rango = o.angMax - o.angMin;
  if (rango < 1.0f) return clampf(salida[i] / 180.0f, 0.0f, 1.0f);
  float centro = (o.angMin + o.angMax) * 0.5f;
  float medio  = rango * 0.5f * 1.25f;
  return clampf((salida[i] - (centro - medio)) / (2.0f * medio), 0.0f, 1.0f);
}
#endif

/*  Se llama en cada ciclo de 50 Hz, después de escribir los servos,
 *  así que refleja el ángulo realmente comandado — incluido el recorte
 *  del limitador de velocidad. Si la onda aparece aplanada en el
 *  osciloscopio, es que el servo está saturado de verdad.
 */
void actualizarMonitor() {
#if MONITOR_OSC
  uint32_t a = (uint32_t)(normalizarServo(cfg.monA) * PWM_MAX);
  uint32_t b = (uint32_t)(normalizarServo(cfg.monB) * PWM_MAX);
#if ESP_ARDUINO_VERSION_MAJOR >= 3
  ledcWrite(PIN_MON_A, a);
  ledcWrite(PIN_MON_B, b);
#else
  ledcWrite(MON_CH_A, a);
  ledcWrite(MON_CH_B, b);
#endif
#endif
}

// ==================================================
//  ESTRIDULACIÓN
// ==================================================
void tonoOn(uint16_t hz) {
  uint32_t d = (uint32_t)(PWM_MAX * clampf(snd.volPct / 200.0f, 0.02f, 0.5f));
#if ESP_ARDUINO_VERSION_MAJOR >= 3
  ledcWriteTone(PIN_BUZZER, hz);
  ledcWrite(PIN_BUZZER, d);
#else
  ledcWriteTone(CH_BUZZER, hz);
  ledcWrite(CH_BUZZER, d);
#endif
}

void tonoOff() {
#if ESP_ARDUINO_VERSION_MAJOR >= 3
  ledcWrite(PIN_BUZZER, 0);
#else
  ledcWrite(CH_BUZZER, 0);
#endif
}

/*  Arranca una frase completa: nChirps ráfagas separadas por gapMs.
 *  En modo "por paso" se llama una vez por ciclo de marcha.
 */
void dispararFrase() {
  if (!snd.activo) return;
  sndFrase    = true;
  sndChirpN   = 0;
  sndEnChirp  = true;
  sndTFase    = micros();
  sndTPulso   = sndTFase;
}

void callarSonido() {
  sndFrase = false;
  sndEnChirp = false;
  if (sndPulsoOn) { tonoOff(); sndPulsoOn = false; }
}
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
void loop() {
  dns.processNextRequest();
  server.handleClient();
  ws.loop();

  // El sonido se actualiza en cada vuelta: la gatilla de pulsos necesita
  // resolución de milisegundo y no puede esperar al ciclo de 50 Hz.
  actualizarSonido();

  static uint32_t tPrev = 0;
  uint32_t ahora = micros();
  if (ahora - tPrev >= 20000UL) {          // 50 Hz, alineado con la trama del servo
    float dt = (ahora - tPrev) / 1000000.0f;
    tPrev = ahora;
    if (dt > 0.1f) dt = 0.1f;
    actualizarMovimiento(dt);
    actualizarOjos(dt);
  }

  static uint32_t tTel = 0;
  uint32_t intervalo = (caminando || mezcla > 0.001f) ? 60 : 300;
  if (millis() - tTel >= intervalo) {
    tTel = millis();
    if (ws.connectedClients() > 0) enviarEstado();
  }
}

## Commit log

2026-09-22 POLO: escarabajo robot caminante open source
    Firmware ESP32-C3, esquematico, diseno y Gerber de la PCB, imagenes,
    README y licencia MIT.
2026-09-22 README bilingue: ingles y espanol con enlaces de salto
2026-09-23 Actualiza Gerber de la PCB (corrige error de la version anterior)
2026-09-23 Actualiza Gerber: elimina instrucciones que apuntaban a JLCPCB
    PCBWay es el patrocinador del proyecto.
2026-09-23 Agrega archivos 3D: modelo Fusion 360 (STEP), STL y perfil OrcaSlicer
    - 3d/POLO.step (modelo CAD completo)
    - 3d/stl/ (piezas individuales) + 3d/polo-stl.zip
    - 3d/POLO_impresion_orcaslicer.3mf (perfil de impresion y bandeja)
    - 3d/README.md con notas de impresion y disclaimer (ES/EN)
    [Acoples lobulares.stl, Biela derecha.stl, Biela izquierda_.stl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]
2026-09-23 Actualiza modelo Fusion 360 (POLO.step): corrige error de la version anterior
